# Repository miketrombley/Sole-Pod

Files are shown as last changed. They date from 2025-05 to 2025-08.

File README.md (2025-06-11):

# Sole Pod Control System

An ESP32-based firmware for controlling a smart pod system with motorized door and tray, LED lighting, and wireless connectivity.

## 🚀 Features

### Core Functionality
- **Motorized Door & Tray Control**: Automated opening/closing sequence with precise position control
- **Smart LED Lighting**: Full-color NeoPixel LED with adjustable brightness and color
- **Hall Sensor Feedback**: Precise position detection for door and tray states
- **Safety Systems**: Motor stall detection with automatic shutdown
- **Persistent Settings**: All configurations saved to flash memory

### Connectivity
- **Bluetooth Low Energy (BLE)**: Local device control via mobile app
- **WiFi Integration**: Network connectivity with credential management
- **AWS IoT Core**: Cloud connectivity for remote monitoring and control
- **MQTT Communication**: Real-time state updates and commands

### User Interface
- **Physical Buttons**: Manual door and LED control
- **Child Lock**: Safety feature to prevent accidental operation
- **Status Indicators**: Real-time feedback on device state

## 📋 Hardware Requirements

### Compatible Hardware
- **Control Board**: v1.4
- **LED Board**: v1.2  
- **Hall Sensor Board**: v1.0
- **Microcontroller**: ESP32

### Pin Configuration
```cpp
// Motor Control
#define DOOR_MOTOR 46          // Door motor control
#define DOOR_DIRECTION 3       // Door motor direction
#define TRAY_MOTOR 10          // Tray motor control  
#define TRAY_DIRECTION 11      // Tray motor direction

// Sensors
#define SW_DOOR_CLOSED 45      // Door closed sensor
#define SW_DOOR_OPENED 48      // Door opened sensor
#define SW_TRAY_CLOSED 35      // Tray closed sensor
#define SW_TRAY_OPENED 36      // Tray opened sensor

// User Interface
#define DOOR_BTN 47            // Door control button
#define LED_BTN 21             // LED control button
#define LED_DATA_PIN 14        // NeoPixel data pin

// Safety
#define VOLTAGE_PIN 9          // Motor current monitoring
```

## 🏗️ Architecture

### System States
The pod operates in 5 distinct states:
1. **CLOSED** (0): Door closed, tray closed
2. **DOOR_MIDWAY** (1): Door transitioning, tray closed  
3. **DOOR_OPEN** (2): Door open, tray closed
4. **TRAY_MIDWAY** (3): Door open, tray transitioning
5. **OPEN** (4): Door open, tray open

### Operation Sequence
**Opening**: CLOSED → DOOR_MIDWAY → DOOR_OPEN → TRAY_MIDWAY → OPEN
**Closing**: OPEN → TRAY_MIDWAY → DOOR_OPEN → DOOR_MIDWAY → CLOSED

## 📱 BLE Interface

### Service UUID
`7d840001-11eb-4c13-89f2-246b6e0b0000`

### Characteristics
| Function | UUID | Type | Range | Description |
|---|---|---|---|---|
| Door Status | `7d840002-...0001` | R/W | 0-1 | 0=Closed, 1=Open |
| Door Position | `7d840003-...0002` | R/W | 50,100 | Partial/Full open |
| LED Status | `7d840004-...0003` | R/W | 0-1 | 0=Off, 1=On |
| LED Brightness | `7d840005-...0004` | R/W | 0-100 | Brightness percentage |
| LED Color | `7d840006-...0005` | R/W | Hex | 6-digit hex color code |
| WiFi Credentials | `7d840007-...0006` | W | String | Format: `SSIDENDNETWORKPASSWORDENDPASSWORD` |
| WiFi Status | `7d840008-...0007` | R/N | String | Connection status |

## ☁️ AWS IoT Integration

### Device Shadow Topics
- **Publish**: `$aws/things/pod_1/shadow/update`
- **Subscribe**: `$aws/things/pod_1/shadow/update/accepted`

### Shadow Document Structure
```json
{
  "state": {
    "reported": {
      "is_open": true,
      "nightlight": false,
      "color": "FF0000",
      "nightlight_brightness": 75
    },
    "desired": {
      "is_open": false,
      "nightlight": true,
      "color": "0000FF",
      "nightlight_brightness": 50
    }
  }
}
```

## 🔧 Configuration

### AWS Configuration
Update `aws_config.h` with your AWS IoT settings:
```cpp
#define AWS_IOT_ENDPOINT "your-endpoint-ats.iot.region.amazonaws.com"
#define DEVICE_NAME "your_device_name"
```

Replace the certificate and key constants with your device-specific credentials.

### WiFi Configuration
Default credentials can be set in `main.cpp`:
```cpp
const char* defaultSSID = "your_network";
const char* defaultPassword = "your_password";
```

## 🛡️ Safety Features

### Motor Stall Detection
- **Threshold**: 0.2V (configurable in `VoltageReader.h`)
- **Sampling**: 50-sample average for noise reduction
- **Response**: Immediate motor shutdown and system lockout
- **Recovery**: Requires power cycle after stall detection

### Child Lock
- Prevents accidental button operation
- Configurable via software flag
- Applies to both door and LED controls

## 📊 Debug Output

Enable debug mode in `main.cpp`:
```cpp
#define DEBUG_MODE true
```

### Debug Information Includes:
- Current pod state and target
- Sensor readings (door/tray positions)
- LED status (state, brightness, color)
- WiFi connection status and signal strength
- Motor voltage readings
- Safety system status

## 🔄 State Persistence

The system automatically saves and restores:
- LED color and brightness settings
- Door position preference (50% or 100% open)
- LED on/off state
- Door open/closed status

Settings are stored in ESP32 flash memory using the Preferences library.

## 🚦 Status Codes

### Safety Status
- `0`: OK - Normal operation
- `1`: Motor stall detected
- `2`: Obstacle detected  
- `3`: Overcurrent condition
- `4`: System error

### WiFi Status
- "Connected" - Successfully connected
- "Disconnected" - Not connected
- "Connection failed" - Failed to connect
- "SSID not available" - Network not found

## 🛠️ Development

### Dependencies
- Arduino ESP32 Core
- WiFiClientSecure
- PubSubClient (MQTT)
- ArduinoJson
- Adafruit NeoPixel
- ESP32 BLE Arduino
- Preferences

### Building
1. Install ESP32 board package in Arduino IDE
2. Install required libraries
3. Configure AWS certificates in `aws_config.h`
4. Upload to ESP32 device

### Testing
- Use serial monitor at 115200 baud for debug output
- Test BLE connectivity with compatible mobile app
- Verify AWS IoT connection in AWS Console
- Test all physical controls and sensors

## 📝 License

TBD

## 🤝 Contributing

[Add contribution guidelines if applicable]

## 📞 Support

[Add support contact information]

---

**Hardware Compatibility**: Control Board v1.4, LED Board v1.2, Hall Sensor Board v1.0

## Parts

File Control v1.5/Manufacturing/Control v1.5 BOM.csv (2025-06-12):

Designator | Footprint | Quantity | Value | LCSC Part #
C1, C2, C3 | C603 | 3 | 10u 25V | C96446
C4, C5 | C603 | 2 | 100n 50V | C14663
D1, D4 | D805 | 2 | 1N5819 | C2927280
D2 | D_SMB | 1 | SMBJ13A | C152108
D3 | D603 | 1 | LED | C497922
D5, D6 | D805 | 2 | 1N914 | C2128
D7, D8 | SOD-123 | 2 | 1N4001W | C18199085
J1, J3, J4 | JST_PH_B2B-PH-K_1x02_P2.00mm_Vertical | 3 | JST-B2B-PH-K | C131337
J10, J11 | JST_XH_B2B-XH-A_1x02_P2.50mm_Vertical | 2 | JST-B2B-XH-A | C158012
J12 | PinHeader_1x04_P2.54mm_Vertical | 1 | Conn_01x04_Pin | C2691448
J2 | JST_XH_B3B-XH-A_1x03_P2.50mm_Vertical | 1 | JST-B3B-XH-A | C144394
J5 | USB_C_TYPE-C_16PIN_2MD | 1 | TYPE-C 16PIN 2MD(073) | C2765186
J6, J7, J8 | JST_PH_B3B-PH-K_1x03_P2.00mm_Vertical | 3 | JST-B3B-PH-K | C131339
J9 | JST_PH_B4B-PH-K_1x04_P2.00mm_Vertical | 1 | JST-B4B-PH-K | C131334
K1, K2 | Relay_DPDT_Omron_G6K-2F-Y | 2 | G6K-2F-Y-TR DC12 | C397192
Q1, Q2, Q3, Q4 | SOT-23-3 | 4 | FMMT617 | C686650
R1, R5 | R603 | 2 | 10k | C25804
R2, R3 | R603 | 2 | 5k1 | C25905
R4, R7, R8, R9 | R603 | 4 | 220R | C22962
R6 | 1206 | 1 | 1R | C17928
SW1 | SW_SPST_B3U-1000P | 1 | RESET | C231329
SW2 | SW_SPST_B3U-1000P | 1 | BOOT | C231329
U1 | SOT-223-3_TabPin2 | 1 | LD1117S33CTR | C35879
U2 | SOT-23-6 | 1 | USBLC6-2SC6 | C2827654
U3 | ESP32-S3-WROOM-1 | 1 | ESP32-S3-WROOM-1-N16R8 | C2913202

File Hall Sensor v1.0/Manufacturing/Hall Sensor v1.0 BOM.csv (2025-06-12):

Designator | Footprint | Quantity | Value | LCSC Part #
C1 | C603 | 1 | 100n 50V | C14663
J1, J2, J3 | SolderWirePad_1x01_SMD_1x2mm | 3 | Conn_01x01_Pin | DNP
U1 | SOT-23 | 1 | SK1816 | C75517

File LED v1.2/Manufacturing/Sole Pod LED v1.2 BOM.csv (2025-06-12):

Designator | Footprint | Quantity | Value | LCSC Part #
C1 | C603 | 1 | 10u 25V | C96446
C2 | C603 | 1 | 100n 50V | C14663
J1, J2, J3, J4, J5, J6 | SolderWirePad_1x01_SMD_1x2mm | 6 | Conn_01x01_Pin | DNP
U1 | LED_Inolux_IN-PI554FCH_PLCC4_5.0x5.0mm_P3.2mm | 1 | XL-5050RGBC | C2843785

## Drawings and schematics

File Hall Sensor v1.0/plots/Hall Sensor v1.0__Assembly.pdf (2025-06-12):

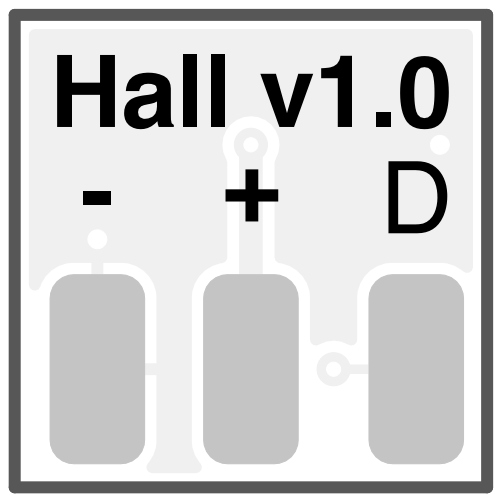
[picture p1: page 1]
Hall v1.0 +; D Date: KiCad; E.D.A. 8.0.3 Size: A4; Rev:

Id: 1/1 Title: File: Hall Sensor v1.0.kicad_pcb Sheet:

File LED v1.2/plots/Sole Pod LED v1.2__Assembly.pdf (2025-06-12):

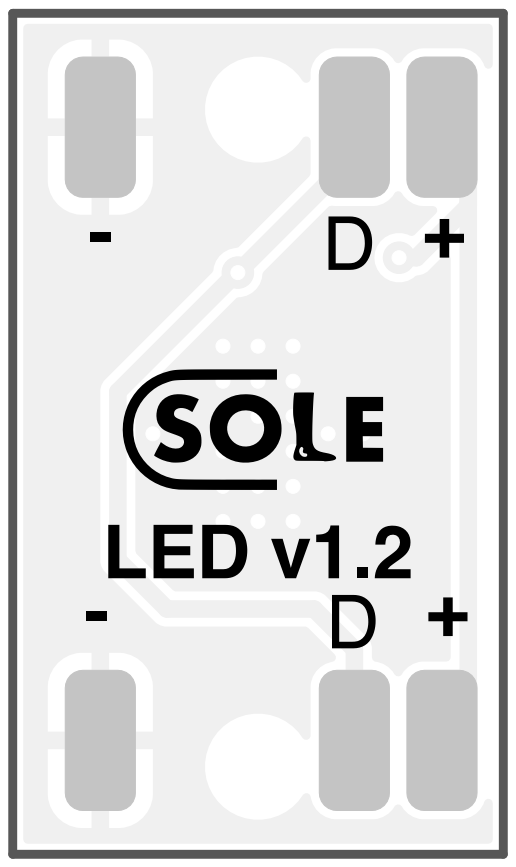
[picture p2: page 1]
LED v1.2; D Date: KiCad; E.D.A. 8.0.3 Size: A4; Rev:; Id: 1/1 Title: File: Sole; Pod; LED v1.2.kicad_pcb Sheet:

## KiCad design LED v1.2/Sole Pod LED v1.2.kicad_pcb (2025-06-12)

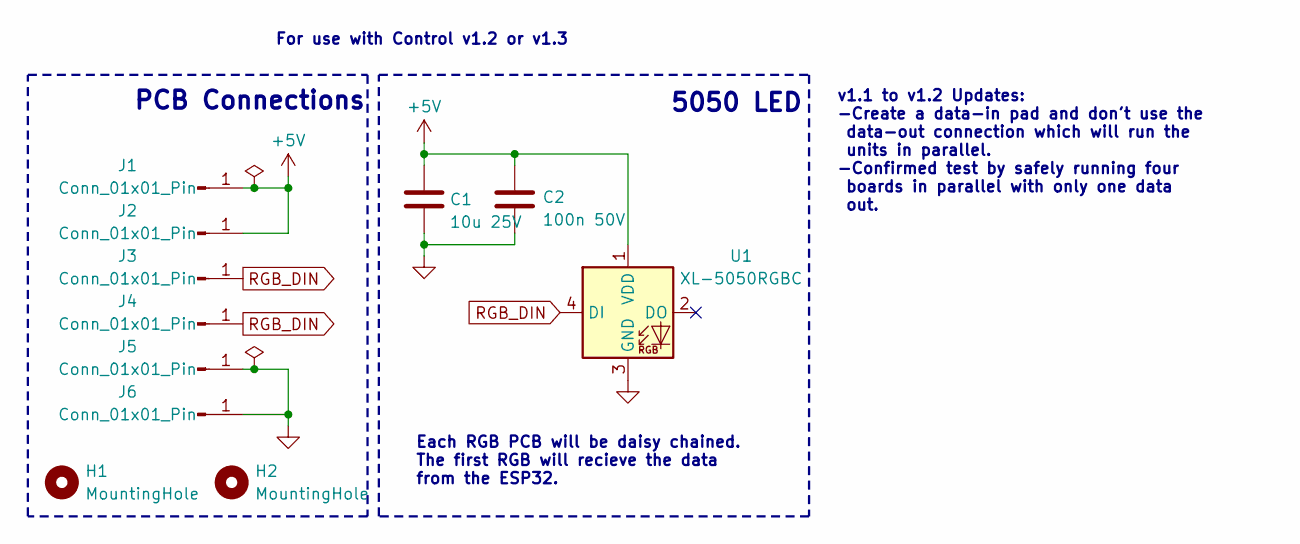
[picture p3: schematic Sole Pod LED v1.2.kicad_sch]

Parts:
C1: 10u 25V; C603; JLCPCB P/N C96446
C2: 100n 50V; C603; JLCPCB P/N C14663
H1, H2: MountingHole; MountingHole_2.5mm; JLCPCB P/N DNP
J1, J2, J3, J4, J5, J6: Conn_01x01_Pin; SolderWirePad_1x01_SMD_1x2mm; JLCPCB P/N DNP
U1: XL-5050RGBC; LED_Inolux_IN-PI554FCH_PLCC4_5.0x5.0mm_P3.2mm; JLCPCB P/N C2843785

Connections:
+5V: C1.1, C2.1, J1.1, J2.1, U1.1 (VDD)
GND: C1.2, C2.2, J5.1, J6.1, U1.3 (GND)
RGB_DIN: J3.1, J4.1, U1.4 (DI)

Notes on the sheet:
v1.1 to v1.2 Updates: -Create a data-in pad and don't use the data-out connection which will run the units in parallel. -Confirmed test by safely running four boards in parallel with only one data out.
PCB Connections
Each RGB PCB will be daisy chained. The first RGB will recieve the data from the ESP32.
5050 LED
For use with Control v1.2 or v1.3

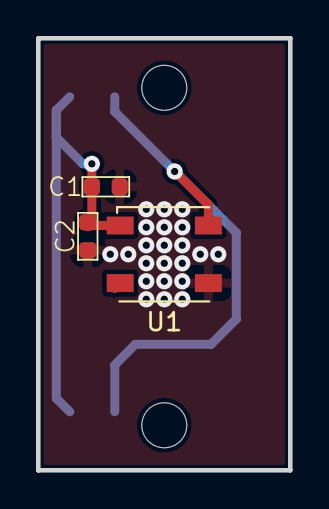
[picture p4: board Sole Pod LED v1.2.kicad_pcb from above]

Board: 2 copper layers, 14.0 x 24.0 mm, 11 parts (0 on the bottom side), 3 nets.

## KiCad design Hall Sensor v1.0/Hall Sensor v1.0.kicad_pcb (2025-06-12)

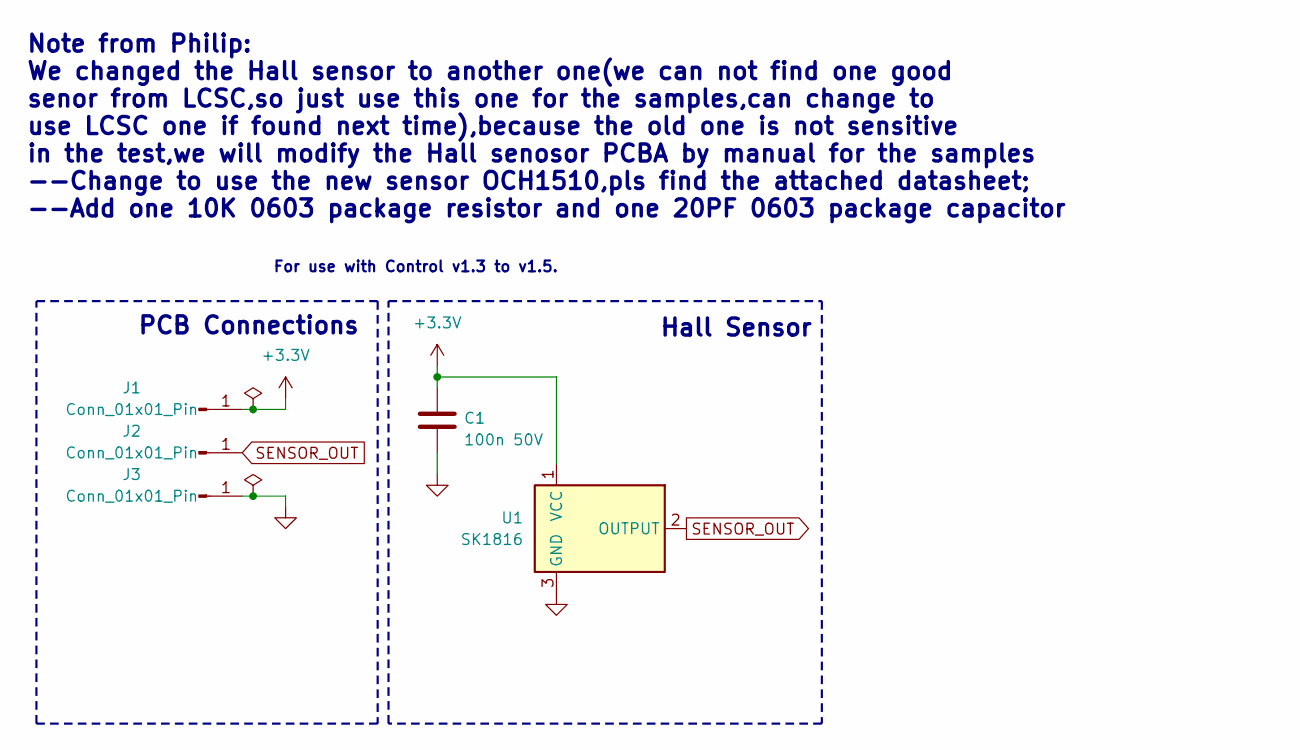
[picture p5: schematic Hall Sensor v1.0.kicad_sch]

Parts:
C1: 100n 50V; C603; JLCPCB P/N C14663
J1, J2, J3: Conn_01x01_Pin; SolderWirePad_1x01_SMD_1x2mm; JLCPCB P/N DNP
U1: SK1816; SOT-23; JLCPCB P/N C75517

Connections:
+3.3V: C1.1, J1.1, U1.1 (VCC)
GND: C1.2, J3.1, U1.3 (GND)
SENSOR_OUT: J2.1, U1.2 (OUTPUT)

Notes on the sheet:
PCB Connections
Hall Sensor
Note from Philip: We changed the Hall sensor to another one(we can not find one good senor from LCSC,so just use this one for the samples,can change to use LCSC one if found next time),because the old one is not sensitive in the test,we will modify the Hall senosor PCBA by manual for the samples --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
For use with Control v1.3 to v1.5.

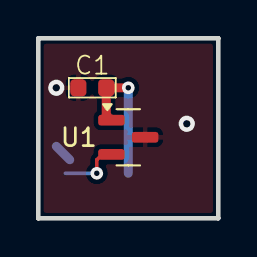
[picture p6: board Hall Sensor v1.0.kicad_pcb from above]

Board: 2 copper layers, 10.0 x 10.0 mm, 5 parts (0 on the bottom side), 3 nets.

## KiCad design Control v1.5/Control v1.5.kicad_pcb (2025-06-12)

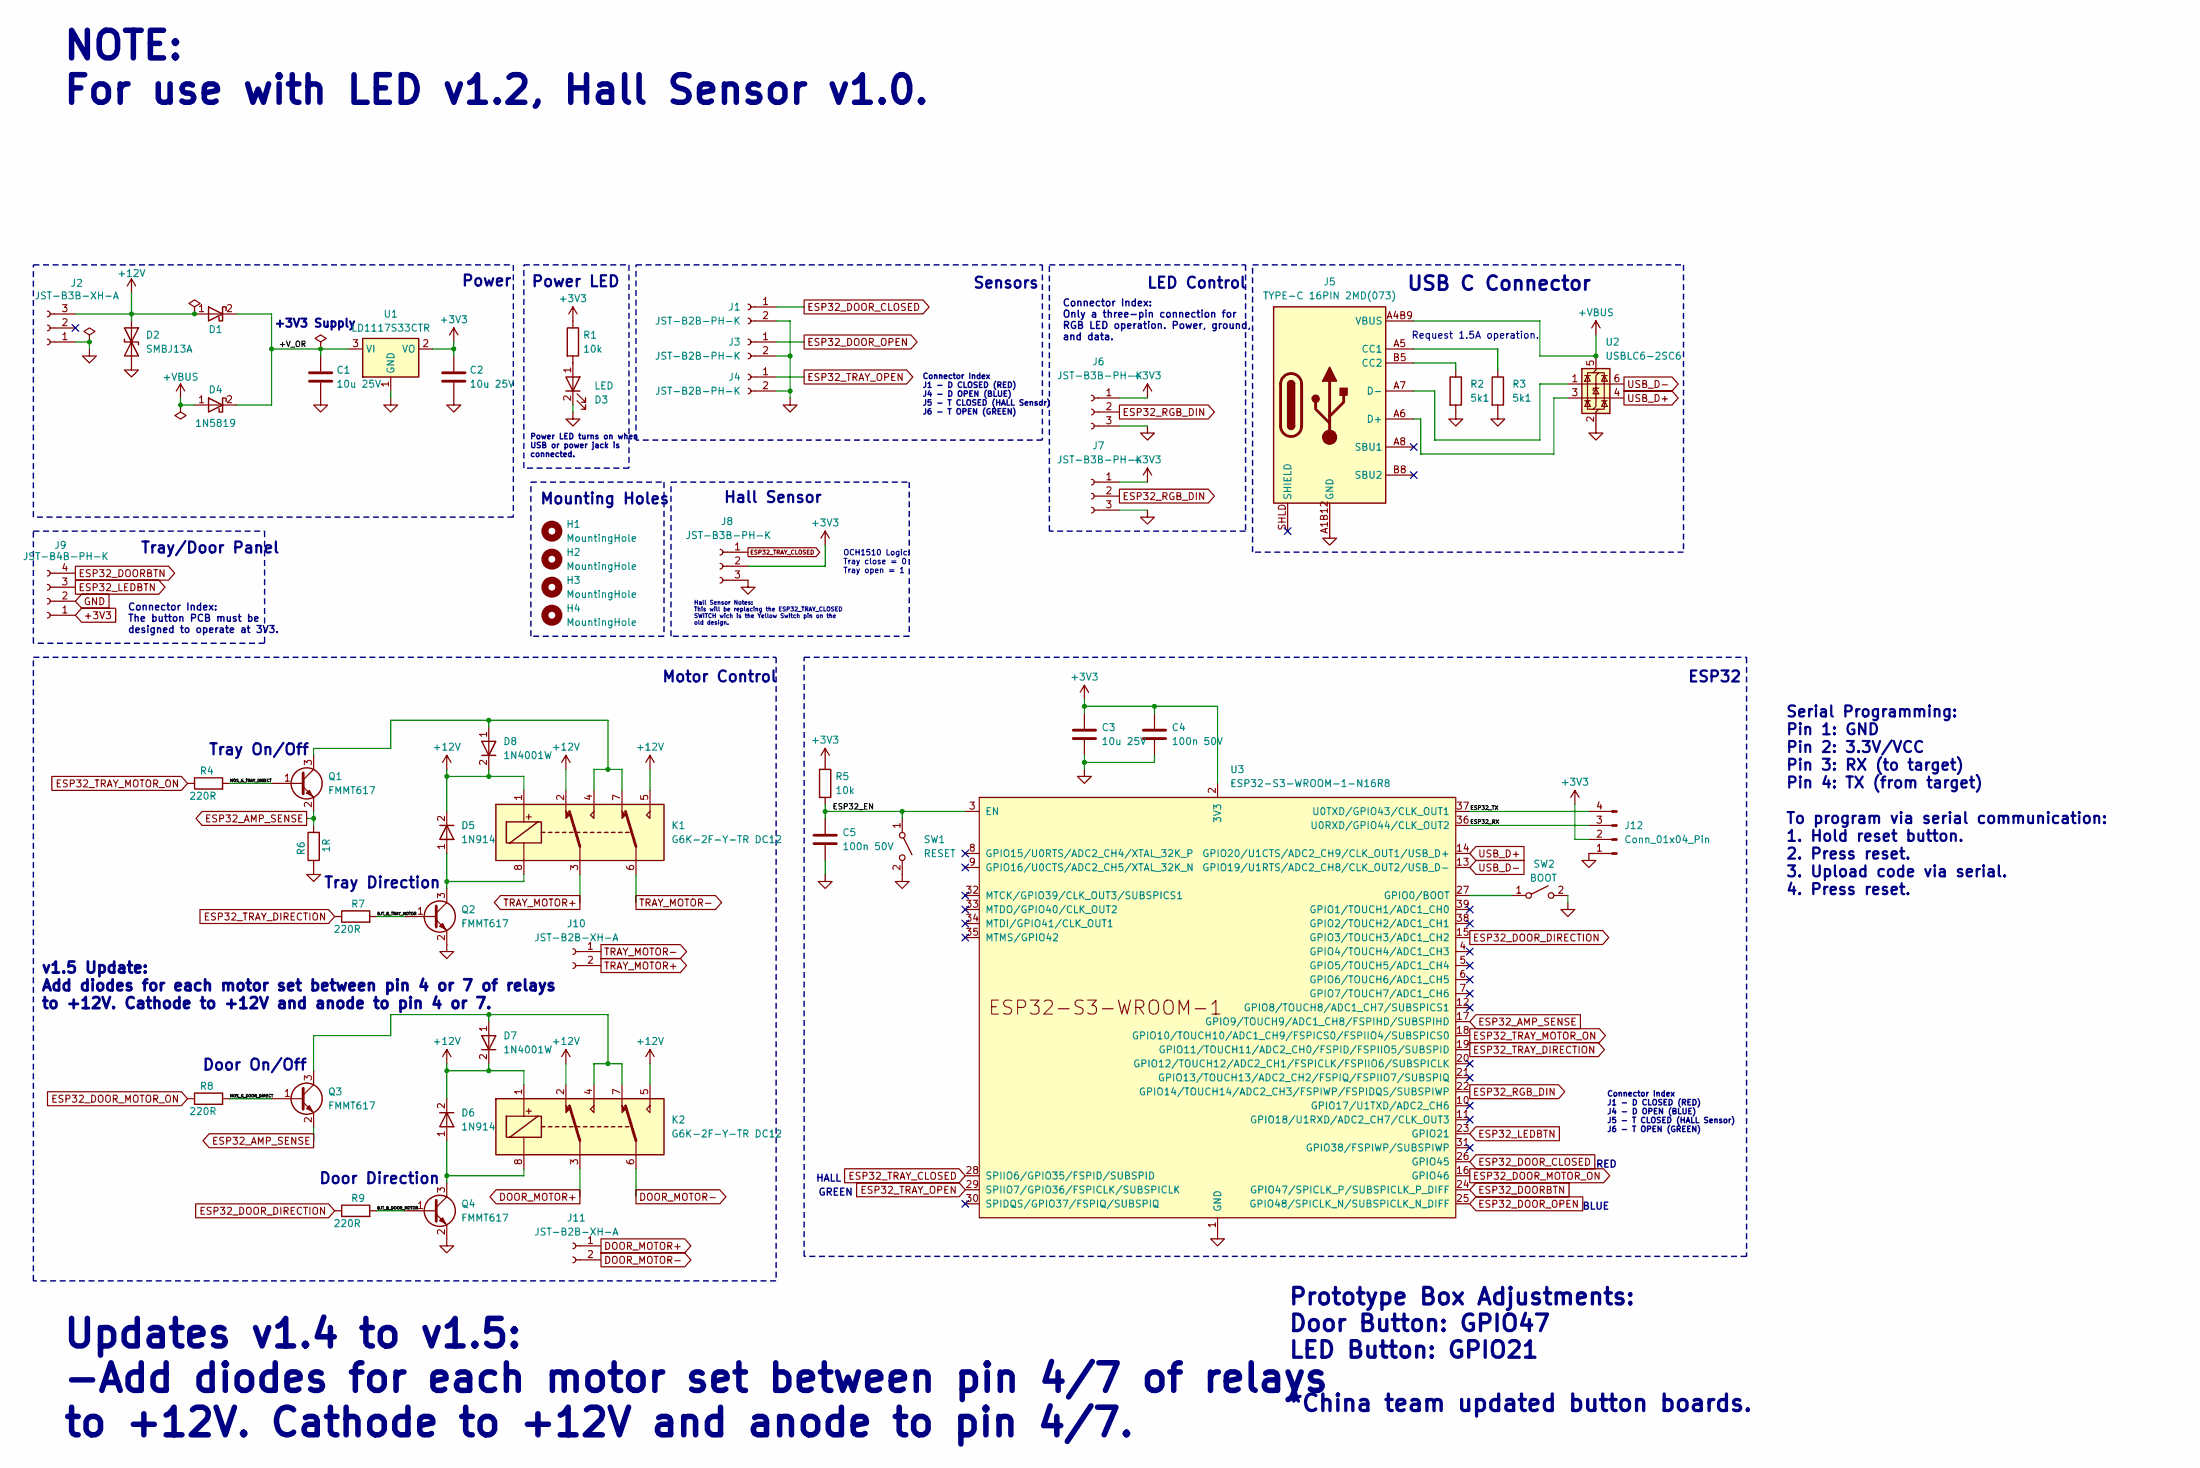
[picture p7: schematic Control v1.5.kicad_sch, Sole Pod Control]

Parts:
C1, C2, C3: 10u 25V; C603; LCSC Part # C96446
C4, C5: 100n 50V; C603; LCSC Part # C14663
D1, D4: 1N5819; D805; LCSC Part # C2927280
D2: SMBJ13A; D_SMB; LCSC Part # C152108
D3: LED; D603; LCSC Part # C497922
D5, D6: 1N914; D805; LCSC Part # C2128
D7, D8: 1N4001W; SOD-123; LCSC Part # C18199085
H1, H2, H3, H4: MountingHole; MountingHole_3mm; LCSC Part # DNP
J1, J3, J4: JST-B2B-PH-K; JST_PH_B2B-PH-K_1x02_P2.00mm_Vertical; LCSC Part # C131337
J2: JST-B3B-XH-A; JST_XH_B3B-XH-A_1x03_P2.50mm_Vertical; LCSC Part # C144394
J5: TYPE-C 16PIN 2MD(073); USB_C_TYPE-C_16PIN_2MD; LCSC Part # C2765186
J6, J7, J8: JST-B3B-PH-K; JST_PH_B3B-PH-K_1x03_P2.00mm_Vertical; LCSC Part # C131339
J9: JST-B4B-PH-K; JST_PH_B4B-PH-K_1x04_P2.00mm_Vertical; LCSC Part # C131334
J10, J11: JST-B2B-XH-A; JST_XH_B2B-XH-A_1x02_P2.50mm_Vertical; LCSC Part # C158012
J12: Conn_01x04_Pin; PinHeader_1x04_P2.54mm_Vertical; LCSC Part # C2691448
K1, K2: G6K-2F-Y-TR DC12; Relay_DPDT_Omron_G6K-2F-Y; LCSC Part # C397192
Q1, Q2, Q3, Q4: FMMT617; SOT-23-3; LCSC Part # C686650
R1, R5: 10k; R603; LCSC Part # C25804
R2, R3: 5k1; R603; LCSC Part # C25905
R4, R7, R8, R9: 220R; R603; LCSC Part # C22962
R6: 1R; R_1206_3216Metric; LCSC Part # C17928
SW1: RESET; SW_SPST_B3U-1000P; LCSC Part # C231329
SW2: BOOT; SW_SPST_B3U-1000P; LCSC Part # C231329
U1: LD1117S33CTR; SOT-223-3_TabPin2; LCSC Part # C35879
U2: USBLC6-2SC6; SOT-23-6; LCSC Part # C2827654
U3: ESP32-S3-WROOM-1-N16R8; ESP32-S3-WROOM-1; LCSC Part # C2913202

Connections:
+3V3: C2.1, C3.1, C4.1, J6.1, J7.1, J8.2, J9.1, J12.2, R1.1, R5.1, U1.2 (VO), U3.2 (3V3)
+12V: D1.1, D2.1 (A1), D5.2 (K), D6.2 (K), D7.2 (K), D8.2 (K), J2.3, K1.1, K1.2, K1.5, K2.1, K2.2, K2.5
+VBUS: D4.1, J5.A4B9 (VBUS), J5.B4A9 (VBUS), U2.5 (VBUS)
/+V_OR: C1.1, D1.2, D4.2, U1.3 (VI)
/BJT_B_DOOR_MOTOR: Q4.1 (B), R9.2
/BJT_B_TRAY_MOTOR: Q2.1 (B), R7.2
/ESP32_EN: C5.1, R5.2, SW1.1 (A), U3.3 (EN)
/ESP32_RX: J12.3, U3.36 (U0RXD/GPIO44/CLK_OUT2)
/ESP32_TX: J12.4, U3.37 (U0TXD/GPIO43/CLK_OUT1)
/MOS_G_DOOR_DIRECT: Q3.1 (B), R8.2
/MOS_G_TRAY_DIRECT: Q1.1 (B), R4.2
DOOR_MOTOR+: J11.1, K2.3
DOOR_MOTOR-: J11.2, K2.6
ESP32_AMP_SENSE: Q1.2 (E), Q3.2 (E), R6.2, U3.17 (GPIO9/TOUCH9/ADC1_CH8/FSPIHD/SUBSPIHD)
ESP32_DOORBTN: J9.4, U3.24 (GPIO47/SPICLK_P/SUBSPICLK_P_DIFF)
ESP32_DOOR_CLOSED: J1.1, U3.26 (GPIO45)
ESP32_DOOR_DIRECTION: R9.1, U3.15 (GPIO3/TOUCH3/ADC1_CH2)
ESP32_DOOR_MOTOR_ON: R8.1, U3.16 (GPIO46)
ESP32_DOOR_OPEN: J3.1, U3.25 (GPIO48/SPICLK_N/SUBSPICLK_N_DIFF)
ESP32_LEDBTN: J9.3, U3.23 (GPIO21)
ESP32_RGB_DIN: J6.2, J7.2, U3.22 (GPIO14/TOUCH14/ADC2_CH3/FSPIWP/FSPIDQS/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)
ESP32_TRAY_CLOSED: J8.1, U3.28 (SPIIO6/GPIO35/FSPID/SUBSPID)
ESP32_TRAY_DIRECTION: R7.1, U3.19 (GPIO11/TOUCH11/ADC2_CH0/FSPID/FSPIIO5/S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)
ESP32_TRAY_MOTOR_ON: R4.1, U3.18 (GPIO10/TOUCH10/ADC1_CH9/FSPICS0/FSPIIO4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)
ESP32_TRAY_OPEN: J4.1, U3.29 (SPIIO7/GPIO36/FSPICLK/SUBSPICLK)
GND: C1.2, C2.2, C3.2, C4.2, C5.2, D2.2 (A2), D3.2 (K), J1.2, J2.1, J3.2, J4.2, J5.A1B12 (GND), J5.B1A12 (GND), J6.3, J7.3, J8.3, J9.2, J12.1, Q2.2 (E), Q4.2 (E), R2.2, R3.2, R6.1, SW1.2 (B), SW2.2 (B), U1.1 (GND), U2.2 (GND), U3.1 (GND), U3.40 (GND), U3.41 (GND)
unnamed: D3.1 (A), R1.2
unnamed: D5.1 (A), K1.8, Q2.3 (C)
unnamed: D6.1 (A), K2.8, Q4.3 (C)
unnamed: D7.1 (A), K2.4, K2.7, Q3.3 (C)
unnamed: D8.1 (A), K1.4, K1.7, Q1.3 (C)
unnamed: J5.A5 (CC1), R3.1
unnamed: J5.B5 (CC2), R2.1
unnamed: J5.A6 (D+), J5.B6 (D+), U2.3 (I/O2)
unnamed: J5.A7 (D-), J5.B7 (D-), U2.1 (I/O1)
unnamed: SW2.1 (A), U3.27 (GPIO0/BOOT)
TRAY_MOTOR+: J10.2, K1.3
TRAY_MOTOR-: J10.1, K1.6
USB_D+: U2.4 (I/O2), U3.14 (GPIO20/U1CTS/ADC2_CH9/CLK_OUT1/USB_D+)
USB_D-: U2.6 (I/O1), U3.13 (GPIO19/U1RTS/ADC2_CH8/CLK_OUT2/USB_D-)

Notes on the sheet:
Tray On/Off
ESP32
HALL
NOTE: For use with LED v1.2, Hall Sensor v1.0.
USB C Connector
Connector Index: Only a three-pin connection for RGB LED operation. Power, ground, and data.
BLUE
Mounting Holes
Tray Direction
v1.5 Update: Add diodes for each motor set between pin 4 or 7 of relays to +12V. Cathode to +12V and anode to pin 4 or 7.
Connector Index J1 - D CLOSED (RED) J4 - D OPEN (BLUE) J5 - T CLOSED (HALL Sensor) J6 - T OPEN (GREEN)
Updates v1.4 to v1.5: -Add diodes for each motor set between pin 4/7 of relays to +12V. Cathode to +12V and anode to pin 4/7.
Connector Index: The button PCB must be designed to operate at 3V3.
Motor Control
Request 1.5A operation.
GREEN
OCH1510 Logic: Tray close = 0 Tray open = 1
Power LED
Sensors
Door Direction
Serial Programming: Pin 1: GND Pin 2: 3.3V/VCC Pin 3: RX (to target) Pin 4: TX (from target) To program via serial communication: 1. Hold reset button. 2. Press reset. 3. Upload code via serial. 4. Press reset.
Hall Sensor
Tray/Door Panel
Power LED turns on when USB or power jack is connected.
Hall Sensor Notes: This will be replacing the ESP32_TRAY_CLOSED SWITCH wich is the Yellow Switch pin on the old design.
Door On/Off
+3V3 Supply
Power
RED
Prototype Box Adjustments: Door Button: GPIO47 LED Button: GPIO21 *China team updated button boards.
LED Control

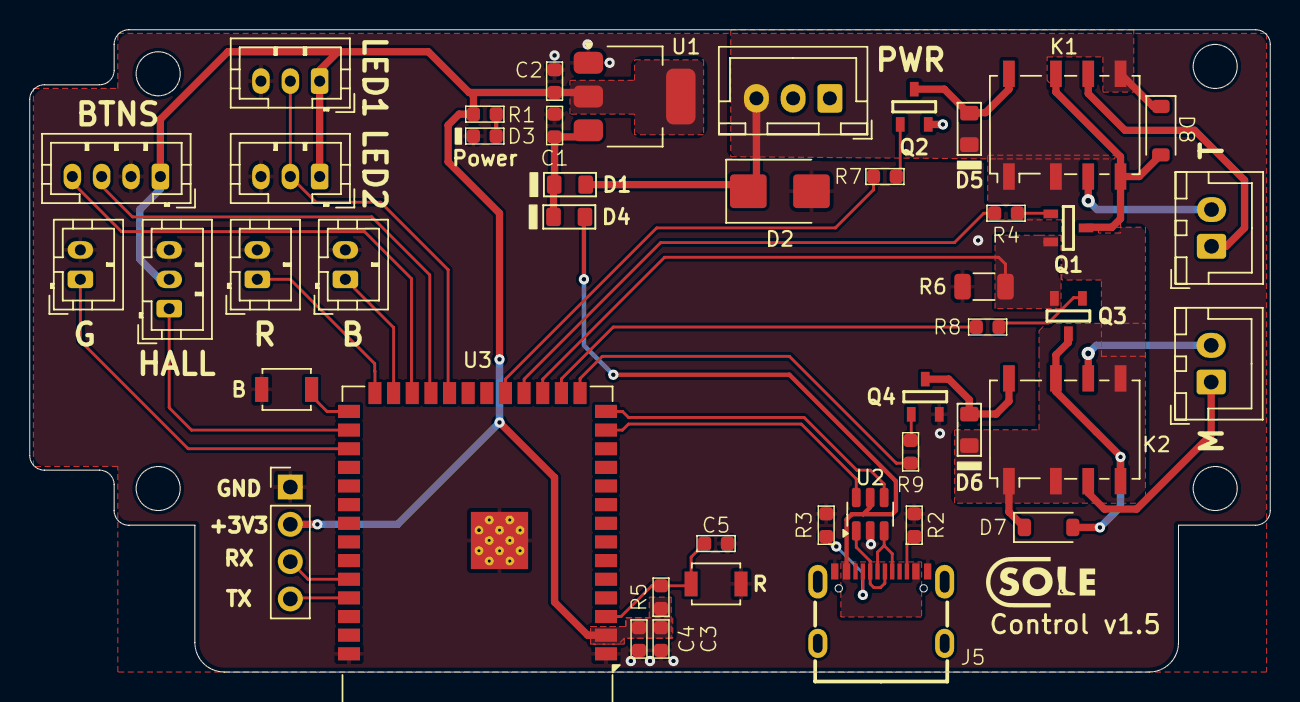
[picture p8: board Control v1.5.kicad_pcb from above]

Board: 2 copper layers, 84.5 x 43.8 mm, 49 parts (0 on the bottom side), 40 nets.

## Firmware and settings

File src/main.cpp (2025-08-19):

/*
Sole Pod Control System
Hardware compatibility:
- Control Board v1.4
- LED Board v1.2
- Hall Sensor Board v1.0

Description:
This firmware controls the Sole Pod system, managing door motors,
tray motors, LED lighting, safety sensors, and BLE connectivity.
*/

#include <Arduino.h>
#include "MotorControl.h"
#include "Sensors.h"
#include "LEDControl.h"
#include "VoltageReader.h"
#include "BLEControl.h" 
#include "SystemSettings.h"
#include "WiFiControl.h"
#include "aws_service.h"
#include "nvs_flash.h"
#include "FS.h"
#include "SPIFFS.h"

#include <WiFiClientSecure.h>
#include <PubSubClient.h>

// Configuration settings
#define DEBUG_MODE true       // Enable/disable debug messages
#define LOOP_DELAY_MS 10      // Main loop delay in milliseconds

// System state flags
bool childLockOn = false;     // Child lock status (true = locked)
bool podOpenFlag = false;     // Pod position flag (true = open, false = closed)

// SSID and password to store
const char* defaultSSID = "";
const char* defaultPassword = "";

//static bool bleActive = false;
static bool fleetProvisioningDone = false;
String thingName, deviceCert, deviceKey;
static bool systemInitialized = false;

// Create WiFi controller instance
WiFiControl wifiControl;

// Update BLEControl instantiation to include child lock reference
BLEControl bleControl(&podOpenFlag, &wifiControl, &childLockOn);

// Function prototypes
void setupSystem();
void runDoorControl();
void runLEDControl();
void runWiFiControl();  // New function for WiFi monitoring
void runChildLockControl(); // New function for child lock state monitoring
void printDebugInfo();

bool hasProvisionedCerts() {
    deviceCert = readStringFromNVS(NVS_NAMESPACE, "deviceCert");
    deviceKey = readStringFromNVS(NVS_NAMESPACE, "deviceKey");
    thingName  = readStringFromNVS(NVS_NAMESPACE, "thingName");

    return (!deviceCert.isEmpty() && !deviceKey.isEmpty() && !thingName.isEmpty());
}

bool AWSconnection() {
    thingName = readStringFromNVS(NVS_NAMESPACE, "thingName");
    deviceCert = readStringFromNVS(NVS_NAMESPACE, "deviceCert");
    deviceKey = readStringFromNVS(NVS_NAMESPACE, "deviceKey");
    root_ca = readFileToString("/root_ca.pem");

    if (deviceCert.length() == 0 || deviceKey.length() == 0 || root_ca.length() == 0) {
        Serial.println("\n Missing cert, key or root CA");
        return false;
    }

    Serial.println("\n Thing Name:");
    Serial.println(thingName);
    Serial.println("\n Device Cert:");
    Serial.println(deviceCert);
    Serial.println("\n Device Key:");
    Serial.println(deviceKey);
    Serial.println("\n Root CA:");
    Serial.println(root_ca);

    net.setCACert(root_ca.c_str());
    net.setCertificate(deviceCert.c_str());
    net.setPrivateKey(deviceKey.c_str());

    client.setServer(aws_endpoint, 8883);
    client.setBufferSize(4096);
    client.setCallback(mqttCallback);
    
    if (!client.connect(thingName.c_str())) {
        Serial.println("\n Failed to connect MQTT.");
        Serial.println(client.state());
        return false;
    }

    Serial.println("\n Connected MQTT with new cert.");
    client.subscribe("testat/topic");
    const char* jsonPayload = "{\"message\":\"Hello from device\"}";

    String shadowDeltaTopic = String("$aws/things/") + thingName + "/shadow/update/delta";
    client.subscribe(shadowDeltaTopic.c_str());
    Serial.printf("Subscribed to Shadow Delta topic: %s\n", shadowDeltaTopic.c_str());

    bool pubSuccess = client.publish("testat/topic", jsonPayload);
    if (pubSuccess) {
        Serial.println("\n Published JSON message to testat/topic");
    } else {
        Serial.println("\n Failed to publish JSON message");
    }

    if (!systemInitialized) {
        setupSystem();
        systemInitialized = true;
    }

    publishReportedState("sneaker_pot_12345678", led_state, led_brightness, led_color, podOpenFlag, childLockOn);

    return true;
}


void ResetChildLock() {
    if (WiFi.status() != WL_CONNECTED && fleetProvisioningDone) {
        if (childLockOn) { 
            Serial.println("WiFi lost connection. Disabling child lock.");
            childLockOn = false;
            saveChildLockState(childLockOn);  
        }
    }
}

void setup() {
    // Initialize serial communication
    Serial.begin(115200);
    bleControl.begin();
    //bleActive = true;
    // Wait for serial connection when in debug mode
    if (DEBUG_MODE) {
        delay(1000);  // Give time for serial monitor to connect
        Serial.println("Sole Pod System Starting...");
    }
    
    if (!SPIFFS.begin(true)) {
        Serial.println("\n SPIFFS Mount Failed");
    
    }
    esp_err_t ret = nvs_flash_init();
    if (ret == ESP_ERR_NVS_NO_FREE_PAGES || ret == ESP_ERR_NVS_NEW_VERSION_FOUND) {
        Serial.println("\n NVS init failed. Erasing and reinitializing...");
        ESP_ERROR_CHECK(nvs_flash_erase());
        ret = nvs_flash_init();
    }
    ESP_ERROR_CHECK(ret);
    Serial.println("\n NVS initialized.");
    
    // Start WiFi connection process without waiting
    if (DEBUG_MODE) {
        Serial.println("Starting WiFi connection in background...");
    }
    
    // Use the non-blocking connection method
    if (wifiControl.loadCredentialsFromNVS()) {
            Serial.println("Connecting to saved WiFi credentials...");
            wifiControl.beginConnection(wifiControl.getCurrentSSID(), wifiControl.getCurrentPassword());
        } else {
            // Nếu chưa có, dùng default (hoặc chờ BLE provisioning)
            wifiControl.beginConnection(defaultSSID, defaultPassword);
        }   
    
    if (DEBUG_MODE) {
        Serial.println("System initialization complete!");
        Serial.print("Motor stall detection threshold set to: ");
        Serial.println(STALL_VOLTAGE_THRESHOLD);
    }
}

void loop() {

    if (wifiControl.getWiFiStatus() == WL_CONNECTED && !fleetProvisioningDone) {
        if (hasProvisionedCerts()) {
            Serial.println("\n Certificate is already in NVS. Connecting to AWS...");
            if (AWSconnection()) {
                Serial.println("\n Connected to AWS successfully!");
                fleetProvisioningDone = true;
            } else {
                Serial.println("\n Failed to connect to AWS. Will retry later.");
            }        
        } else {
            Serial.println("\n No certificate found. Performing Fleet Provisioning...");
            if (runFleetProvisioning()) {
                Serial.println("\n Fleet provisioning done!");
                delay(1000);
                ESP.restart(); // Khởi động lại để dùng cert mới
            } else {
                Serial.println("\n Fleet provisioning failed!");
            }
        }
        //fleetProvisioningDone = true;
    }
    
    ResetChildLock();
    
    client.loop();
    // Run safety checks
    //runSafetyChecks();
    
    if (systemInitialized) {
        // Handle door control functionality
        runDoorControl();
        
        // Handle LED control functionality
        runLEDControl();
    }
    
    // Handle WiFi connection monitoring
    runWiFiControl();
    
    // Handle child lock state monitoring
    //runChildLockControl();
    
    // Check and update JSON status characteristic (NEW)
    //bleControl.checkJSONUpdate();
    
    // Print debug information if enabled
    if (DEBUG_MODE) {
        printDebugInfo();
    }
    
    // Small delay to stabilize loop timing
    delay(LOOP_DELAY_MS);
}

void runWiFiControl() {
    static unsigned long lastWiFiCheckTime = 0;
    static String lastWiFiStatus = "";
    static bool initialConnectionAttempt = true;
    static unsigned long connectionStartTime = 0;
    static int reconnectAttempts = 0;          
    const int MAX_RECONNECT_ATTEMPTS = 3;
    const unsigned long WIFI_CHECK_INTERVAL = 5000; // Check more frequently during initial connection
    const unsigned long CONNECTION_TIMEOUT = 10000; // 10 second timeout
    
    unsigned long currentTime = millis();
    
    // Handle initial connection attempt
    if (initialConnectionAttempt) {
        if (connectionStartTime == 0) {
            connectionStartTime = currentTime;
        }
        
        // Check if connected
        if (wifiControl.getWiFiStatus() == WL_CONNECTED) {
            initialConnectionAttempt = false;
            reconnectAttempts = 0;
            if (DEBUG_MODE) {
                Serial.println("\n WiFi connected successfully in background!");
                Serial.printf("Network: %s\n", wifiControl.getCurrentSSID().c_str());
                Serial.printf("IP Address: %s\n", wifiControl.getLocalIP().toString().c_str());
            }
        }
        // Check for timeout
        else if (currentTime - connectionStartTime > CONNECTION_TIMEOUT) {
            initialConnectionAttempt = false;
            if (DEBUG_MODE) {
                Serial.println("\n Initial WiFi connection attempt timed out.");
            }
        }
    }
    
    // Regular WiFi status check (less frequent after initial setup)
    if (currentTime - lastWiFiCheckTime >= WIFI_CHECK_INTERVAL) {
        String currentStatus;

        if (wifiControl.getWiFiStatus() == WL_CONNECTED) {
            currentStatus = "CONNECTED:" + wifiControl.getCurrentSSID() + ":" +
                            wifiControl.getLocalIP().toString();
            reconnectAttempts = 0; 
            
        } else {
            currentStatus = "\n DISCONNECTED";
            
            // Nếu không phải initial attempt và có credentials
            if (!initialConnectionAttempt && wifiControl.getCurrentSSID().length() > 0) {
                if (reconnectAttempts < MAX_RECONNECT_ATTEMPTS) {
                    if (DEBUG_MODE) {
                        Serial.printf("WiFi connection lost! Attempting reconnect %d/%d...\n",
                                      reconnectAttempts + 1, MAX_RECONNECT_ATTEMPTS);
                    }
                    wifiControl.beginConnection(wifiControl.getCurrentSSID(), wifiControl.getCurrentPassword());
                    reconnectAttempts++;
                } else {
                    // Quá số lần thử → xóa WiFi credentials trong NVS
                    if (DEBUG_MODE) {
                        Serial.println("Max reconnect attempts reached. Clearing saved WiFi credentials.");
                    }
                    wifiControl.clearCredentialsFromNVS();  // Hàm xóa NVS (cần thêm vào WiFiControl)
                    //wifiControl.beginConnection("", "");     // Ngắt kết nối, chờ BLE provisioning mới
                    reconnectAttempts = 0;
                }
            }
        }
        
        // Chỉ cập nhật BLE nếu trạng thái thay đổi
        if (lastWiFiStatus != currentStatus) {
            bleControl.updateWiFiStatus(currentStatus);
            lastWiFiStatus = currentStatus;
        }
        
        lastWiFiCheckTime = currentTime;
    }
}

// void runChildLockControl() {
//     static bool prevChildLockState = false; // Track previous child lock state
//     static bool firstRun = true; // Flag to force first update
    
//     // Update BLE child lock status if the state has changed or first run
//     if (prevChildLockState != childLockOn || firstRun) {
//         // Update BLE characteristic
//         bleControl.updateChildLock(childLockOn);
        
//         // Save child lock state to persistent storage
//         saveChildLockState(childLockOn);
        
//         // Update previous state for next iteration
//         prevChildLockState = childLockOn;
//         firstRun = false;
//     }
// }

void setupSystem() {
    // Initialize sensors
    initSwitches();
    
    // Initialize motor control
    initMotors();
    
    // Initialize voltage monitoring
    initVoltageReader();
    
    // Initialize settings module
    initSettings();
    
    // Load saved settings including child lock state
    String savedLedColor;
    uint8_t savedLedBrightness;
    uint8_t savedDoorPosition;
    uint8_t savedLedState;
    bool savedDoorStatus;
    bool savedChildLock;
    
    if (loadAllSettings(savedLedColor, savedLedBrightness, savedDoorPosition, 
                       savedLedState, savedDoorStatus, savedChildLock)) {
        // Apply loaded settings to the global variables
        ledColorHex = savedLedColor;
        ledBrightness = savedLedBrightness;
        doorPosition = savedDoorPosition;
        // No need to set lightState here - we'll call setLEDState after initialization
        podOpenFlag = savedDoorStatus; // Set the door status based on saved value
        childLockOn = savedChildLock; // Set the child lock status based on saved value
    }
    
    // Initialize LED control
    initLEDs();
    
    // Explicitly set the LED state based on saved setting (defaults to OFF)
    setLEDState(savedLedState);
    
    // Initialize BLE control
    // if (wifiControl.getWiFiStatus() != WL_CONNECTED) {
    //         bleControl.begin();
    //         bleActive = true;
    //         Serial.println("\n BLE started!");
    // } else {
    //         bleActive = false;
    //         Serial.println("\n WiFi already connected - BLE disabled.");
    // }
}

// Handle door related functionality
void runDoorControl() {
    static uint8_t prevState = POD_STATE_UNDEFINED;
    static bool prevOpenFlag = false;
    static uint8_t prevDoorPosition = 0; 
    
    // Process door button input
    handleDoorButton(podOpenFlag, childLockOn);
    manageMotors(podOpenFlag);
    
    // Read current door state
    uint8_t currentState = readState();
    uint8_t currentDoorPosition = getDoorPosition();
    
    // Update BLE door status if:
    // 1. The physical door state has changed OR
    // 2. The target state (podOpenFlag) has changed
    if (prevState != currentState || prevOpenFlag != podOpenFlag) {
        // Determine if door is considered "open" for BLE status
        // Door is "open" when:
        // - It's physically open (POD_STATE_DOOR_OPEN or further)
        // - OR it's in transition and the target is "open" (podOpenFlag = true)
        bool doorIsOpenForBLE = false;
        
        if (currentState == POD_STATE_DOOR_OPEN || 
            currentState == POD_STATE_TRAY_MIDWAY || 
            currentState == POD_STATE_OPEN) {
            // Door is physically open or further in open state
            doorIsOpenForBLE = true;
        } 
        else if (currentState == POD_STATE_DOOR_MIDWAY) {
            // Door is in transition - use the target state
            doorIsOpenForBLE = podOpenFlag;
        }
        
        // Update BLE status
        bleControl.updateDoorStatus(doorIsOpenForBLE);
        
        // Save door status if the flag has changed
        if (prevOpenFlag != podOpenFlag) {
            saveDoorStatus(podOpenFlag);
        }
        
        // Update previous values for next iteration
        prevState = currentState;
        prevOpenFlag = podOpenFlag;
    }

    // Update BLE door position if it has changed
    if (prevDoorPosition != currentDoorPosition) {
        bleControl.updateDoorPosition(currentDoorPosition);
        prevDoorPosition = currentDoorPosition;
    }
}

void runLEDControl() {
    static uint8_t prevLEDState = 255; // Initialize with an invalid state to force first update
    static uint8_t prevLEDBrightness = 101; // Track previous brightness
    static String prevLEDColor = ""; // Track previous color
    
    // Process LED button input
    handleLEDButton(childLockOn);
    
    // Read current LED state, brightness, and color
    uint8_t currentLEDState = getLEDState();
    uint8_t currentLEDBrightness = getLEDBrightness();
    String currentLEDColor = getLEDColor();
    
    // Update BLE LED status if the LED state has changed
    if (prevLEDState != currentLEDState) {
        // Update BLE
        bleControl.updateLEDStatus(currentLEDState);
        
        // Update previous state for next iteration
        prevLEDState = currentLEDState;
    }
    
    // Update BLE LED brightness if the brightness has changed
    if (prevLEDBrightness != currentLEDBrightness) {
        // Brightness is already in 0-100 range, no scaling needed
        bleControl.updateLEDBrightness(currentLEDBrightness);
        
        // Update previous brightness for next iteration
        prevLEDBrightness = currentLEDBrightness;
    }
    
    // Update BLE LED color if the color has changed
    if (prevLEDColor != currentLEDColor) {
        // Update BLE
        bleControl.updateLEDColor(currentLEDColor);
        
        // Update previous color for next iteration
        prevLEDColor = currentLEDColor;
    }
}

// Print debug information to serial console
void printDebugInfo() {
    static unsigned long lastDebugTime = 0;
    static bool lastBLEConnectionStatus = false;
    bool currentBLEStatus = bleControl.getConnectionStatus(); // Get BLE status
    
    // Only update debug info every 500ms to avoid flooding serial
    if (millis() - lastDebugTime > 5000) {
        uint8_t currentState = readState();
        float voltage = readAverageVoltage();
        
        if (wifiControl.getWiFiStatus() == WL_CONNECTED) {
            Serial.println("--- System Status ---");
            
            Serial.print("Pod State: ");
            Serial.print(getStateDescription(currentState));
            Serial.print(" (");
            Serial.print(currentState);
            Serial.println(")");
            Serial.print("LED State: ");
            Serial.print(getLEDState() == LED_STATE_ON ? "ON" : "OFF");
            Serial.print("LED Brightness: ");
            Serial.println(getLEDBrightness());
            Serial.println(")");
            Serial.print("LED Color: ");
            Serial.println(getLEDColor());
            Serial.print("Target: ");
            Serial.println(podOpenFlag ? "OPENING/OPEN" : "CLOSING/CLOSED");
            Serial.print("Child Lock: ");
            Serial.println(childLockOn ? "ENABLED" : "DISABLED");
            Serial.print("Door Position: ");
            Serial.println(getDoorPosition());
            Serial.print("LED State: ");
            Serial.println(getLEDState() == LED_STATE_ON ? "ON" : "OFF");
            Serial.print("LED Brightness: ");
            Serial.println(getLEDBrightness());
            
            // Print individual sensor states
            Serial.println("Sensors:");
            Serial.print("  Door Closed: ");
            Serial.println(isDoorClosed() ? "ACTIVE" : "INACTIVE");
            Serial.print("  Door Open: ");
            Serial.println(isDoorOpen() ? "ACTIVE" : "INACTIVE");
            Serial.print("  Tray Closed: ");
            Serial.println(isTrayClose() ? "ACTIVE" : "INACTIVE");
            Serial.print("  Tray Open: ");
            Serial.println(isTrayOpen() ? "ACTIVE" : "INACTIVE");
        }

        // Add WiFi status to debug info
        Serial.print("WiFi Status: ");
        Serial.println(wifiControl.getWiFiStatusString());
        if (wifiControl.getWiFiStatus() == WL_CONNECTED) {
            Serial.print("Network: ");
            Serial.println(wifiControl.getCurrentSSID());
            Serial.print("IP Address: ");
            Serial.println(wifiControl.getLocalIP().toString());
            Serial.print("Signal Strength: ");
            Serial.print(wifiControl.getSignalStrength());
            Serial.println(" dBm");
        }

        // Detect BLE connection changes
        if (lastBLEConnectionStatus != currentBLEStatus) {
            if (currentBLEStatus) {
                Serial.println("*** BLE CLIENT CONNECTED ***");
            } else {
                Serial.println("*** BLE CLIENT DISCONNECTED - ADVERTISING RESUMED ***");
            }
            lastBLEConnectionStatus = currentBLEStatus;
        }
        
        Serial.println("-------------------");
        
        lastDebugTime = millis();
    }
}

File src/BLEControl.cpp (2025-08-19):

#include "BLEControl.h"
#include "MotorControl.h"
#include "LEDControl.h"


// BLE Server Callbacks Implementation
void BLEServerCallback::onConnect(BLEServer* pServer) {
    if (bleControl) {
        uint16_t clientId = pServer->getConnId();
        bleControl->handleClientConnect(clientId);
    }
}

// void BLEServerCallback::onDisconnect(BLEServer* pServer) {
//     if (bleControl) {
//         bleControl->handleClientDisconnect();
//     }
// }

// BLE Characteristic Callbacks Implementation
void BLECharacteristicCallback::onWrite(BLECharacteristic* characteristic) {
    if (!bleControl) return;
    
    std::string uuid = characteristic->getUUID().toString();
    
    if (uuid == UUID_DOOR_STATUS) {
        bleControl->handleDoorStatusWrite(characteristic);
    }
    else if (uuid == UUID_DOOR_POSITION) {
        bleControl->handleDoorPositionWrite(characteristic);
    }
    else if (uuid == UUID_LIGHTS) {
        bleControl->handleLEDStatusWrite(characteristic);
    }
    else if (uuid == UUID_LIGHTS_BRIGHTNESS) {
        bleControl->handleLEDBrightnessWrite(characteristic);
    }
    else if (uuid == UUID_LIGHTS_COLOR) {
        bleControl->handleLEDColorWrite(characteristic);
    }
    else if (uuid == UUID_WIFI_CREDENTIALS) {
        bleControl->handleWiFiCredentialsWrite(characteristic);
    }
    else if (uuid == UUID_CHILD_LOCK) {
        bleControl->handleChildLockWrite(characteristic);
    }
}

void BLECharacteristicCallback::onRead(BLECharacteristic* characteristic) {
    std::string uuid = characteristic->getUUID().toString();
    std::string value = characteristic->getValue();
    
    // Print the value read from the characteristic
    if (uuid == UUID_DOOR_STATUS) {
        Serial.print("BLE Client read door status: ");
        Serial.println(value.c_str());
    }
    else if (uuid == UUID_DOOR_POSITION) {
        Serial.print("BLE Client read door position: ");
        Serial.println(value.c_str());
    }
    else if (uuid == UUID_LIGHTS) {
        Serial.print("BLE Client read LED status: ");
        Serial.println(value.c_str());
    }
    else if (uuid == UUID_LIGHTS_BRIGHTNESS) {
        Serial.print("BLE Client read LED brightness: ");
        Serial.println(value.c_str());
    }
    else if (uuid == UUID_LIGHTS_COLOR) {
        Serial.print("BLE Client read LED color: ");
        Serial.println(value.c_str());
    }
    else if (uuid == UUID_CHILD_LOCK) {
        Serial.print("BLE Client read child lock status: ");
        Serial.println(value.c_str());
    }
    else if (uuid == UUID_JSON_STATUS) {
        Serial.print("BLE Client read JSON status: ");
        Serial.println(value.c_str());
    }
}

// BLEControl Constructor
BLEControl::BLEControl(bool* podOpenFlag, WiFiControl* wifiControl, bool* childLock) 
    : pServer(nullptr), pAdvertising(nullptr), pDoorStatus(nullptr), pDoorPosition(nullptr), 
      pLEDStatus(nullptr), pLEDBrightness(nullptr), pLEDColor(nullptr), pWiFiCredentials(nullptr), 
      pWiFiStatus(nullptr), pChildLock(nullptr), pJSONStatus(nullptr), isClientConnected(false), connectedClientId(0),
      podOpenFlagRef(podOpenFlag), wifiControlRef(wifiControl), childLockRef(childLock), 
      networkBuffer(""), passwordBuffer(""), lastJSONUpdate(0) {
}

void BLEControl::begin() {
    Serial.println("Initializing BLE...");
    
    // Initialize BLE
    BLEDevice::init("Sole Pod");
    pServer = BLEDevice::createServer();
    
    // Set server callbacks for connection management
    pServer->setCallbacks(new BLEServerCallback(this));

    // Create service with more characteristics support
    static BLEUUID serviceUUID("7d840001-11eb-4c13-89f2-246b6e0b0000");
    BLEService* pService = pServer->createService(serviceUUID, 35, 0); // Increased for JSON characteristic

    // Create all characteristics
    createCharacteristics(pService);
    
    // Set initial values based on current states
    setInitialValues();

    // Start the service
    pService->start();

    // Get advertising instance and configure it
    pAdvertising = BLEDevice::getAdvertising();
    pAdvertising->addServiceUUID(UUID_SERVICE);
    pAdvertising->setScanResponse(true);
    pAdvertising->setMinPreferred(0x06);  // Functions that help with iPhone connections issue
    pAdvertising->setMinPreferred(0x12);
    
    // Start advertising
    startAdvertising();

    Serial.println("BLE Control initialized and advertising started");
}

void BLEControl::createCharacteristics(BLEService* pService) {
    // Create Door Status Characteristic
    pDoorStatus = pService->createCharacteristic(
        UUID_DOOR_STATUS, 
        BLECharacteristic::PROPERTY_WRITE | BLECharacteristic::PROPERTY_READ
    );
    pDoorStatus->setCallbacks(new BLECharacteristicCallback(this, UUID_DOOR_STATUS));
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

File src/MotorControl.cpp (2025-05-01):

#include "MotorControl.h"
#include "Sensors.h"
#include "VoltageReader.h"

// Door position tracking
uint8_t doorPosition = 100; // 0 = Door Closed, 100 = Door Fully Open

// Previous state of the Door button
bool previousDoorBtnState = HIGH;

void initMotors() {
    // Set motor control pins as outputs
    pinMode(DOOR_MOTOR, OUTPUT);
    pinMode(DOOR_DIRECTION, OUTPUT);
    pinMode(TRAY_MOTOR, OUTPUT);
    pinMode(TRAY_DIRECTION, OUTPUT);

    // Initialize all motors to OFF state
    digitalWrite(DOOR_MOTOR, LOW);
    digitalWrite(TRAY_MOTOR, LOW);

    // Initialize door button pin as input with internal pull-up resistor
    pinMode(DOOR_BTN, INPUT_PULLUP);
    
    Serial.println("Motor Control Initialized!");
}

void manageMotors(bool podOpenFlag) {
    // Read the current state of the pod from sensors
    uint8_t currentState = readState();
    
    // Determine whether to open or close pod based on flag
    if (podOpenFlag) {
        podOpen();
    } else {
        podClose();
    }
}

void handleDoorButton(bool &podOpenFlag, bool childLockOn) {
    // Skip processing if child lock is active
    if (childLockOn) {
        return;
    }
    
    // Read the current state of the Door button (active LOW with pull-up)
    bool doorBtnState = !digitalRead(DOOR_BTN);

    // If the button was just pressed (transition from not pressed to pressed)
    if (doorBtnState == LOW && previousDoorBtnState == HIGH) {
        Serial.println("Door Button Pressed");
        podOpenFlag = !podOpenFlag; // Toggle the pod open/close state
    }
    
    // Update the previous button state for next iteration
    previousDoorBtnState = doorBtnState;
}

void stopAllMotors() {
    digitalWrite(DOOR_MOTOR, LOW);
    digitalWrite(TRAY_MOTOR, LOW);
}

// Pod opening sequence
void podOpen() {
    uint8_t currentState = readState();
    
    // Door Opening, Tray Closed (State 0->1->2)
    if (currentState == POD_STATE_CLOSED || currentState == POD_STATE_DOOR_MIDWAY) {
        setPodState(DOOR_OPENING);
    }
    // Door Open, Tray Opening (State 2->3->4)
    else if (currentState == POD_STATE_DOOR_OPEN || currentState == POD_STATE_TRAY_MIDWAY) {
        // Only open tray if door is fully open
        if (doorPosition == 100) {
            setPodState(TRAY_OPENING);
        }
    }
    // Door Open, Tray Open (State 4 - complete)
    else if (currentState == POD_STATE_OPEN) {
        setPodState(MOTORS_OFF);
    }
}

// Pod closing sequence
void podClose() {
    uint8_t currentState = readState();
    
    // Door Open, Tray Open or Closing (State 4->3->2)
    if (currentState == POD_STATE_OPEN || currentState == POD_STATE_TRAY_MIDWAY) {
        // Remove the doorPosition check when closing
        // Always close the tray when closing the pod
        setPodState(TRAY_CLOSING);
    }
    // Door Open or Closing, Tray Closed (State 2->1->0)
    else if (currentState == POD_STATE_DOOR_OPEN || currentState == POD_STATE_DOOR_MIDWAY) {
        setPodState(DOOR_CLOSING);
    }
    // Door Closed, Tray Closed (State 0 - complete)
    else if (currentState == POD_STATE_CLOSED) {
        setPodState(MOTORS_OFF);
    }
}

// Update motor states based on transition type
void setPodState(uint8_t transition) {
    switch (transition) {
        // All motors off
        case MOTORS_OFF:
            digitalWrite(DOOR_MOTOR, LOW);
            digitalWrite(TRAY_MOTOR, LOW);
            break;
            
        // Door opening
        case DOOR_OPENING:
            digitalWrite(DOOR_MOTOR, HIGH);
            //digitalWrite(DOOR_DIRECTION, LOW);  // Direction for opening (old)
            digitalWrite(DOOR_DIRECTION, HIGH);  // Direction for opening
            digitalWrite(TRAY_MOTOR, LOW);
            break;
            
        // Tray opening
        case TRAY_OPENING:
            digitalWrite(DOOR_MOTOR, LOW);
            digitalWrite(TRAY_MOTOR, HIGH);
            digitalWrite(TRAY_DIRECTION, LOW);  // Direction for opening
            break;
            
        // Tray closing
        case TRAY_CLOSING:
            digitalWrite(DOOR_MOTOR, LOW);
            digitalWrite(TRAY_MOTOR, HIGH);
            digitalWrite(TRAY_DIRECTION, HIGH); // Direction for closing
            break;
            
        // Door closing
        case DOOR_CLOSING:
            digitalWrite(DOOR_MOTOR, HIGH);
            //digitalWrite(DOOR_DIRECTION, HIGH); // Direction for closing (old)
            digitalWrite(DOOR_DIRECTION, LOW);  // Direction for opening
            digitalWrite(TRAY_MOTOR, LOW);
            break;
            
        default:
            // Invalid transition - stop all motors for safety
            stopAllMotors();
            break;
    }
}

uint8_t getDoorPosition() {
    return doorPosition;
}

void setDoorPosition(uint8_t position) {
    // Only allow values of 50 or 100
    if (position == 50 || position == 100) {
        doorPosition = position;
        Serial.print("Door position set to: ");
        Serial.println(doorPosition);
        
        // Save only the door position setting
        saveDoorPosition(doorPosition);
    } else {
        Serial.println("Invalid door position! Only 50 or 100 allowed.");
    }
}

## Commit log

2025-05-01 BLE Revision - LED On
2025-05-01 BLE Revision - LED Brightness
2025-05-01 BLE Revision - LED Color
2025-05-01 Load/Save LED Status/Brightness/Color and Door Position.
2025-05-01 Updated motor direction to work with Control v1.4 assemblies.
2025-05-29 Updated LED library for use with NEO pixel.
2025-06-04 Fixed the issue with passing a 0 in LED brightness.
    [BLEControl.cpp, LEDControl.cpp]
2025-06-11 Updated LED control to work with new BLE code.
2025-06-11 Updated LED to use FastLED.
2025-06-12 Added JSON and KiCAD files.
    [Control v1.5 BOM.csv, Control v1.5.kicad_pcb, Control v1.5.kicad_sch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]
2025-08-19 feat: ble and wifi handle
    [partitions.csv]
